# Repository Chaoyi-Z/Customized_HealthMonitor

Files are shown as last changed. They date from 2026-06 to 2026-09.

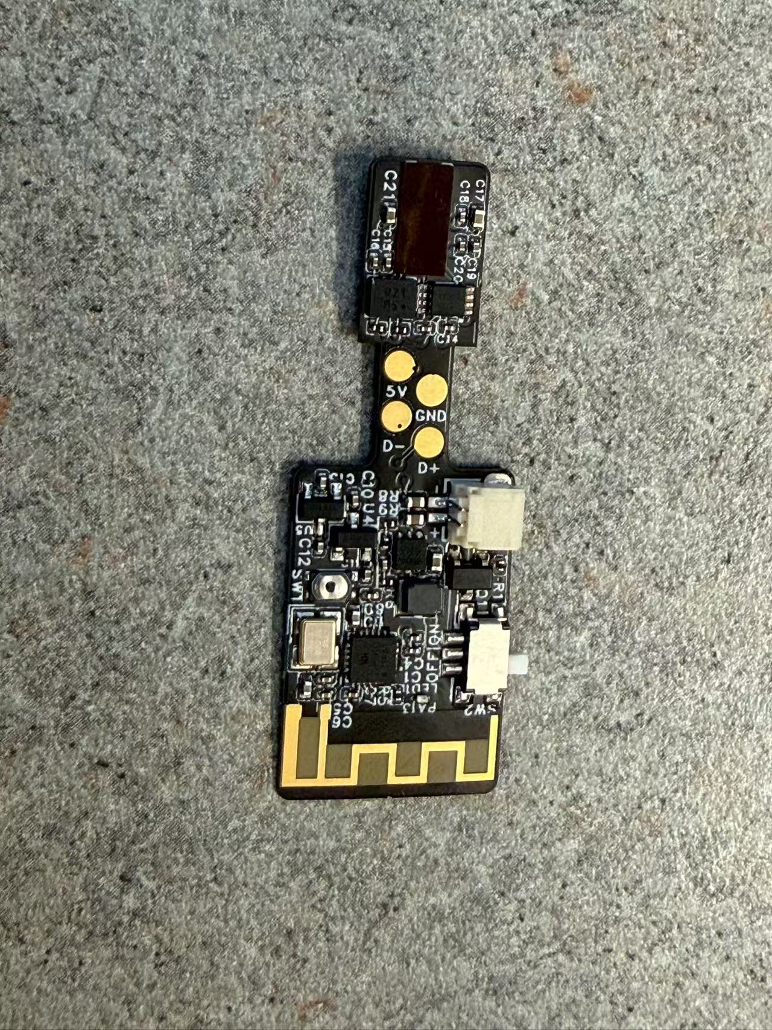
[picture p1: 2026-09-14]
NewBoard/Board_front.jpg

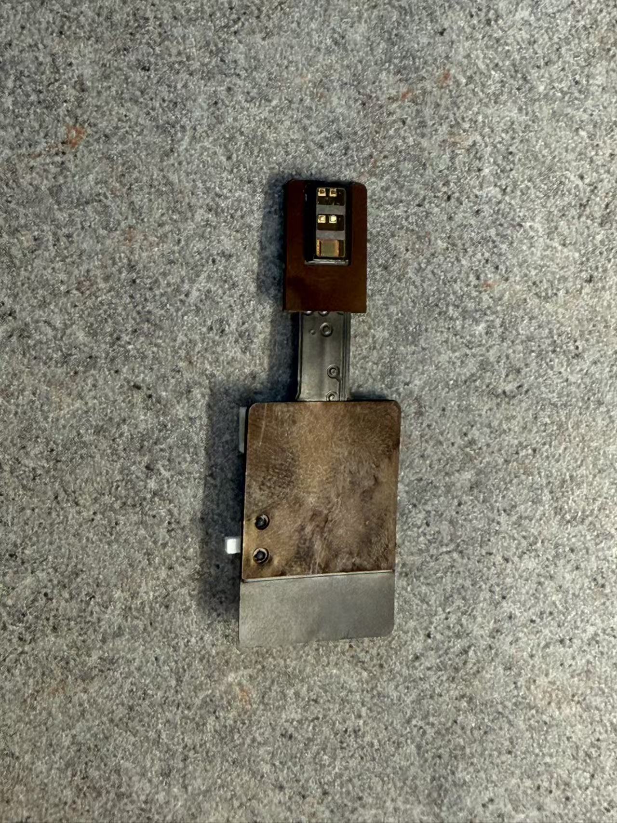
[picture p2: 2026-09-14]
NewBoard/Board_back.jpg

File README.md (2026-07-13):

# ESP32 Health Monitor (BLE)

A wireless physiological monitoring system for marmoset and human subjects. An
ESP32-S3 + MAX30102 streams **Heart Rate, SpO₂, HRV, Skin Temperature, Signal
Quality**, and the **raw PPG waveform** over Bluetooth LE — with real-time
forwarding to [Lab Streaming Layer (LSL)](https://github.com/sccn/labstreaminglayer)
(MonkeyLogic / LabRecorder), **live PC-side beat detection**, and an **offline
NeuroKit2 HRV pipeline**.

---

## Hardware

| Component | Part |
|---|---|
| Microcontroller | ESP32-S3 Dev Module |
| Pulse oximeter | MAX30102 (I²C) |
| Charger | TP4056 (single-cell LiPo) |
| Connection | USB-C (charging + flashing) |

Wiring: MAX30102 SDA → GPIO 8, SCL → GPIO 9 (or as defined in firmware).

---

## Repository layout

```
ESP32_HealthMonitor/ESP32_HealthMonitor.ino   Firmware (Arduino sketch)
health_monitor_gui.py                         Windows BLE GUI + live PC-side HR/HRV
analyze_recording.py                          Offline NeuroKit2 HRV analysis
test_lsl_stream.py                            LSL smoke test
health_monitor_receiver.m                     MATLAB LSL reader
HARDWARE_v2.md, BUDGET_PLAN.md, DEVLOG.md      Design docs / dev log
```

---

## Firmware (`ESP32_HealthMonitor/ESP32_HealthMonitor.ino`)

### Dependencies (Arduino IDE)
- **ESP32 board package** by Espressif (≥ 3.x) — add via Boards Manager
- **SparkFun MAX3010x Pulse and Proximity Sensor Library** — via Library Manager
  ⚠️ If multiple MAX30105 libraries are installed, keep only the SparkFun one.

### Board settings (Arduino IDE 2.x)
| Setting | Value |
|---|---|
| Board | ESP32S3 Dev Module |
| Upload Speed | 460800 |
| USB CDC On Boot | Disabled |
| Port | whichever COM port appears |

### Flashing
**Easiest — Arduino IDE:** open the sketch, pick the board + port, click **Upload**.
The ESP32-S3 uses native USB, so auto-reset often doesn't trigger — if it stalls at
`Connecting…`, do the bootloader dance: **hold BOOT → tap RESET → release BOOT**,
then **re-check Tools → Port** (the COM number can change in bootloader mode) and
Upload again. Use a **USB-C _data_ cable** (many are charge-only).

**Command line (esptool):**
```bash
esptool --chip esp32s3 --port <COM_PORT> --baud 460800 \
  --before no-reset write-flash 0x0 \
  build/esp32.esp32.esp32s3/ESP32_HealthMonitor.ino.merged.bin
```

### BLE service — two characteristics
- **DATA** (NOTIFY, ASCII, ~2.5 Hz) — status string, e.g.:
  ```
  SAMPLING=1,HR=72,SPO2=98,AVG=70,VALID=1,PI=2.4,TEMP=33.5,HRV=38,
  SPECIES=human,CHARGE=battery,FIFO=2,OVF=0,CFG=800/215/1,PROF=4000/300/12000
  ```
- **RAW** (NOTIFY, binary) — the raw PPG waveform in compact little-endian packets
  (3-byte / 18-bit IR & Red samples + real per-sample timestamps + beat markers).
  Lets a host watch the waveform live or re-derive HR/SpO₂/HRV itself.

### Diagnostics (appended to the DATA packet)
| Field | Meaning |
|---|---|
| `CFG=sr/pw/avg` | sensor's **actual** sample rate / pulse width / averaging (register readback) |
| `FIFO=n` | peak MAX30102 FIFO occupancy (of 32) |
| `OVF=n` | cumulative FIFO overflow count (dropped samples) |
| `PROF=r/n/s` | loop profile in µs: per-sample **r**ead / per BLE **n**otify / **S**pO₂ call |

### Sample-rate notes
The effective PPG rate is capped by the **MAX30102's own sample production** — not
BLE, not firmware (confirmed with the diagnostics above: `OVF`=0, tiny notify time,
0% packet loss). The practical sweet spot is **`sampleRate=800, pulseWidth=215µs,
2-LED` → ~250 Hz**. Higher configs counterintuitively produce _slower_. The SparkFun
on-board `checkForBeat()` only tracks reliably near ~20 Hz, so **use the PC-side
detector for HRV** at higher rates. For finer inter-beat timing, the offline analyzer
adds sub-sample peak interpolation.

---

## Python GUI (`health_monitor_gui.py`)

### Install
```bash
pip install bleak pylsl matplotlib numpy scipy
```
Only `bleak` is required; `pylsl` (LSL), `matplotlib` (live plot), and `numpy`/`scipy`
(PC-side HR/HRV) are optional and degrade gracefully if missing.

### Run
```bash
python health_monitor_gui.py
```

### Features
- **PC-side beat detection** — species-aware (bandpass + peak find) HR & HRV computed
  on the host from the raw PPG, independent of the firmware; works at any sample rate.
  This is the **primary HR readout**; the board's own HR is shown as a small diagnostic.
- **Live raw-PPG waveform plot** with beat markers
- Live SpO₂ / PI / Temp / HRV; species toggle (Human / Marmoset)
- **Recording** → status CSV **+** `_raw.csv` (per-sample PPG, with packet `seq`) **+**
  `_beats.csv`; fully instrumented (`cfg`/`fifo`/`ovf`/`prof` columns)
- **Auto-resume** sampling after a BLE reconnect (survives brownout reboots)
- **LSL outlets**: status + raw PPG + beat markers

### LSL channel map (status stream)
| Ch | Label | Unit | Notes |
|----|---|---|---|
| 1 | HR | bpm | −1 = no finger |
| 2 | SpO2 | % | −1 = invalid |
| 3 | HR_avg | bpm | Rolling average |
| 4 | Valid | bool | 1 = good signal |
| 5 | PI | % | Perfusion index |
| 6 | Temp | °C | Skin temperature |
| 7 | HRV | ms | RMSSD |
| 8 | Charge | code | 0=battery 1=charging 2=full |

---

## Offline HRV analysis (`analyze_recording.py`)

Rigorous, publication-grade HRV from a recorded `_raw.csv`, using **NeuroKit2**.

```bash
pip install neurokit2 scipy numpy
python analyze_recording.py path/to/hr_spo2_..._raw.csv [--species human|marmoset]
```

Pipeline: split into device-clock sessions (handles reboots) → gate out
finger-off / low-perfusion segments → species-aware beat detection with **Kubios
artifact correction** and **sub-sample peak interpolation** → full time / frequency /
nonlinear HRV, a per-segment breakdown, and a plot of the longest clean segment.
Species is auto-detected from the companion status CSV.

---

## MonkeyLogic integration

1. Start `health_monitor_gui.py` → click **Start Sampling**
2. In MonkeyLogic **LSL Setup**: set Stream #1 Name = `HealthMonitor`
3. LSL data is auto-recorded in `AnalogData.LSL.LSL1` in the `.bhv2` file

### Read LSL data in MATLAB after recording
```matlab
data = mlread('your_file.bhv2');
all_hr = []; all_spo2 = [];
for i = 1:numel(data)
    lsl = data(i).AnalogData.LSL.LSL1;
    if isempty(lsl), continue; end
    valid = lsl(:,5) == 1;
    all_hr   = [all_hr;   lsl(valid, 2)];   % HR
    all_spo2 = [all_spo2; lsl(valid, 3)];   % SpO2
end
```

---

## Test LSL stream
```bash
python test_lsl_stream.py
```

## Running two boards simultaneously
Give each board a unique name via `DEVICE_NAME` in the firmware and the matching
`DEVICE_NAME` in the GUI; reflash each board. (Default: `HealthMonitor1`.)

---

## Battery life (measured)

On battery at the ~250 Hz config (100 mAh LiPo):
- **~84–92 min total runtime**, reproducible across runs.
- Near end of charge the device **brownout-cycles** — it reboots every ~10–25 min as
  the LiPo sags under load — so only the first ~30 min is unbroken. The GUI's
  auto-resume keeps recording across the reboots.
- Charge _state_ (charging / full / battery) is reported; there is **no battery-%
  gauge** on the v1 board (planned via the BQ25120A PMIC — see `HARDWARE_v2.md`).

| Battery | Rough runtime |
|---|---|
| 100 mAh | ~1.5 hr |
| 200 mAh | ~3 hr |
| 500 mAh | ~5+ hr |

*(~70–90 mA total draw: ESP32-S3 BLE active + MAX30102 LEDs.)*

---

## Authors
- Desimone Lab / Feng Lab, MIT

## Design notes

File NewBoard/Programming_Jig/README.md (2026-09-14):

# Programming jig + battery for the Animal Pulse Sensing flex board (CH591D, Schematic_V3)

## 1. What the debug pads are

The four round pads on the flex neck are the CH591D's **USB** port (PB11 = UD+, PB10 = UD−) plus GND and the board's
own **+5 V boost-converter output** (not a USB power input). The chip is programmed over USB with WCH's ISP bootloader.

Measured from the EasyEDA render (`debug_pad_layout.png`, ±0.05 mm; confirm in EasyEDA before ordering anything):

| Pad | x (mm) | y (mm) | Note |
|-----|---:|---:|---|
| 5V  | −6.09 | −1.21 | boost output — **leave unconnected** |
| GND | −4.50 | +1.11 | |
| D−  | −2.78 | −1.19 | UD− (PB10) |
| D+  | −1.14 | +1.11 | UD+ (PB11) |

Pad Ø 2.15 mm (silk ring Ø 2.39), rows 2.31 mm apart, ~1.65 mm between neighbouring pads along the neck,
neck 5.0 mm wide × ~8 mm long. Coordinates are in the pick-and-place frame (`PickAndPlace_FLEX.xlsx`).

**This is not a standard 2.54 / 2.0 / 1.27 mm pattern, so no off-the-shelf pogo cable or clip fits it.**
Use the printed jig below, or for a one-off flash simply tack-solder three wires (GND, D−, D+) to the pads.

## 2. The jig (files in this folder)

| File | Purpose |
|---|---|
| `pogo_jig_base.stl` | Base plate 56 × 30 × 5 mm with a 0.5 mm pocket in the board outline, a through-slot under the MAX86916, two M3 self-tap holes |
| `pogo_jig_top.stl`  | Pin carrier 7.3 × 28 × 9 mm that drops into the neck notch, 4 pogo holes (Ø1.2) + 2 M3 clearance holes. Already oriented for printing (tongue up) |
| `pogo_jig.scad` | Same geometry, editable. If EasyEDA gives different pad coordinates, edit `pads=[...]` and re-render |
| `pogo_jig_preview.png` | Section views for a sanity check |

Parts to buy:

- 4 × **P75-B1** spring pogo pins (Ø1.02 mm barrel, round head, ~16.5 mm long) — sold in 100-packs on Amazon, e.g. https://www.amazon.com/100pcs-P75-B1-1-02mm-Spring-Loaded/dp/B07BZJ74RC . (Round head "B1" is kinder to gold pads than the pointed "E2".)
- 2 × M3 × 16 mm screws (self-tap into the base plate).
- One sacrificial **USB-A cable** (or a USB-A pigtail). Standard colours: black = GND, white = D−, green = D+, red = +5 V.

The cable (any one of these, see `jig_wiring.png` for the hole-to-wire map):

- **USB-A male to bare-wire pigtail**, e.g. [PATIKIL 3-pack, 28 AWG](https://www.amazon.com/PATIKIL-Pigtail-Extension-Adapter-Charging/dp/B0DWJY8T6Q) or [ELNONE 0.5 m 2-pack](https://www.amazon.com/ELNONE-2Pcs-Short-Pigtail-Wire/dp/B0CKPV3MZR). Thin (28 AWG) is easier to solder to the pin tails than 22–24 AWG.
- **Adafruit 4448 USB-A Plug Breakout Cable** ($1.95, 30 cm, female jumper ends): https://www.adafruit.com/product/4448 . Cut the jumper sockets off and solder the wires, or leave them on and solder a short 0.64 mm header pin to each pogo tail so the sockets push on.
- Any old USB cable cut in half.

Wire colours are standard USB 2.0: pin 1 red = VBUS 5 V, pin 2 white = D−, pin 3 green = D+, pin 4 black = GND. Cheap pigtails sometimes swap colours, so check each wire against the plug pins with a meter first.

Assembly:

1. Print both parts, 0.12–0.2 mm layers, PLA or PETG. If the pin holes print tight, open them with a 1.0 mm drill.
2. Push the pins in from the top until the tips stick out **~1.3 mm below the tongue face** (the raised 4.7 mm strip). Fix with a drop of CA glue on the top side only.
3. Solder black→GND, white→D−, green→D+. **Cut and insulate the red wire** — the board's 5 V pad is an output.
4. Drop the board into the pocket (sensor window down, it goes into the slot), set the pin carrier in the neck notch (the notched corners of both parts go together), tighten the two screws until the carrier sits on the base.

### 2b. Magnetic snap-on version (no screws)

`pogo_jig_base_mag.stl` + `pogo_jig_top_mag.stl` (or set `magnetic=true` in the .scad). Same pad geometry; the two M3 screws are
replaced by two magnet pairs and two alignment pegs. The carrier snaps onto the board one-handed and pulls off with a tilt.

- Magnets: **4 × neodymium discs, Ø4 × 2 mm** (fits `pogo_jig_*_mag.stl`). Amazon listings checked live on 2026-09-03, all Prime-shipped:
  - [MAGNEZMATIC N52 4 mm × 2 mm, 100 pack](https://www.amazon.com/dp/B0HC4G9WGT) — $19.49, 0.94 lb pull each. Best grade; low stock.
  - [AplysiaTech N52 D4×2 mm, 400 pack](https://www.amazon.com/dp/B0F4MYLY85) — $23.99, 4.6★.
  - [BEST CHOICE MAGNETS 4×2 mm, 300 pack](https://www.amazon.com/dp/B0CCXZ1J6N) — $9.99, 4.5★, grade not stated (assume N35, ~70 % of N52 pull; still ample).
  Two N52 pairs give well over 1 kg of clamp against ~0.2–0.4 kg of pogo spring force; N35 still gives roughly 0.7 kg.
  Ø4 × 3 mm discs fit the `pogo_jig_*_mag_4x3.stl` files instead, e.g. [4×3 mm 100 pack](https://www.amazon.com/dp/B0G2RFCBYW) ($9.99, grade not stated) or
  [The Magnet Baron N52 4×3 mm](https://themagnetbaron.com/products/100pcs-4mm-x-3mm-5-32-x-1-8-disc-magnets).
- Pockets: Ø4.15 × 2.1 mm, two in the top face of the base and two in the underside of the carrier, 8 mm either side of the neck centre line.
  Press the magnets in flush and fix with a drop of CA or epoxy. Both faces sit ~0.1 mm below the plastic so the parts mate plastic-to-plastic.
- Alignment: two Ø3 × 2 mm pegs printed on the carrier drop into Ø3.3 holes in the base (12.3 mm either side of centre). Pegs give ±0.15 mm
  registration; the magnets only supply force. If the pegs print oversize, a light pass with a file is enough.
- **Polarity keying**: glue the two base magnets with opposite poles up (north up on the +y side, south up on the −y side), then set the carrier
  magnets so they attract in the correct orientation. A carrier put on backwards is then repelled, which is a second orientation guard on top of the notched corners.
- Keep the magnets on the jig only. A magnet or steel target on the board would add ~0.5–1 g to the wearable, pick up metal debris, and is
  incompatible with any MRI use, which is why a MagSafe-style board connector is not recommended for this device.

## 3. Flashing procedure

- **Never feed USB 5 V into the 5 V pad.** Power the board from its own battery: battery plugged in, USB cable plugged into the PC, then slide SW2 to ON.
- Install **WCHISPTool** (includes the CH372 USB driver): https://www.wch-ic.com/downloads/WCHISPTool_Setup_exe.html .
  Cross-platform CLI alternative: `wchisp` (`wchisp flash firmware.bin`) — https://github.com/ch32-rs/wchisp .
- Chip series CH59x → CH591, interface USB, load the `.hex`/`.bin`, Download.

Bootloader entry facts for the **CH591D (QFN20)**:

- A **blank chip enters the USB bootloader automatically** at power-on (flash address 0 erased). So the first flash of a fresh board "just works".
- Afterwards the bootloader is only entered if **PB7 is low at power-on** (Boot0 for CH591D; PB22 does not exist on this package). PB7 is QFN pin 10 and is **not connected to anything on this board**, so re-flashing needs one of:
  1. Firmware support: e.g. hold SW1 (PA9) at power-on → firmware erases its own first 4 KB (`FLASH_ROM_ERASE(0, 4096)`) and resets, so the bootloader sees blank flash and stays in ISP. (Derived from the documented blank-flash behaviour — test it on the first board before relying on it.) Same thing can be triggered by a BLE command.
  2. Touch QFN pin 10 (PB7) to GND with a fine probe while switching the board on. Awkward on a flex but workable under a scope.
  3. Next board revision: add a PB7 test pad (and ideally a standard 2.54 mm 1×4 or Tag-Connect footprint for the USB pads so a stock pogo clip fits).
- The board's VIO33 rail is 3.0 V, inside the CH591D spec (2.3–3.6 V).

## 4. Battery

CN1 is **JST SH, 1.0 mm pitch, 2-pin, side entry (SM02B-SRSS-TB)**. Mating plug: **JST SHR-02V-S-B**. Input range 3.6–4.2 V (single LiPo).
There is **no charger on the board**, so the cell must be charged externally.

Ready-made cells with the right plug (TinyCircuits, also on Amazon):

| Cell | Size (mm) | Weight | Max discharge | Price | Link |
|---|---|---:|---:|---:|---|
| 150 mAh | 20 × 20 × 5 | 3.8 g | 150 mA | $4.95 | https://tinycircuits.com/products/lithium-ion-polymer-battery-3-7v-150mah |
| 70 mAh  | 15 × 15 × 5 | 1.9 g | 70 mA  | $4.95 | https://tinycircuits.com/products/lithium-ion-polymer-battery-3-7v-70mah |
| 40 mAh  | 20 × 8 × 3.5 | ~1 g | 40 mA | — | https://tinycircuits.com/products/lithium-ion-polymer-battery-3-7v-40mah |

All include a protection PCM. Recommended: **150 mAh** for bench/first animals (headroom for the MAX86916 LED pulses through the 5 V boost), 70 mAh where size matters.
Rough runtime at an estimated 8–20 mA average draw (BLE streaming + PPG + IMU): 150 mAh ≈ 7–18 h, 70 mAh ≈ 3–9 h. Measure it on the real firmware.

Charger with a JST SH socket: **TinyCircuits Tiny Battery Charger** (MCP73831, 100 mA default, micro-USB, $6.95)
https://tinycircuits.com/products/tiny-battery-charger . Adafruit/SparkFun chargers use JST PH 2.0 mm and would need an adapter.

Rolling your own leads: housing **SHR-02V-S-B** + pre-crimped **ASSHSSH28K152** SH jumper (DigiKey), cut in half and soldered to any cell.

**Polarity:** JST SH plugs are not standardised. With the antenna to the right and SW2 at the top, the CN1 pin nearest the neck is
"−" and the outer pin is "+" (silkscreened). Check with a meter that the red lead lands on "+". The board has a P-MOSFET reverse-polarity
guard (Q1), so a swapped plug will not damage anything — it just won't power up; swap the crimps in the housing to fix it.
Switch SW2 OFF before plugging or unplugging the cell.

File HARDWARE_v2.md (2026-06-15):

# ESP32 Health Monitor — Hardware v2 (Shrink Revision)

Target form factor: **~15 × 25 mm main board** + MAX30102 flex tail (unchanged).
Goal: wearable-grade for marmoset harness mounting.

---

## Headline change

Replace **three separate power chips + slide switch + BOOT button** with **one PMIC**:

| v1 (current) | v2 (new) |
|---|---|
| TP4056 (charger, SOP-8) | **BQ25120A** (2.5 × 2.6 mm WCSP-25) |
| ME6217 (3.3V LDO, SOT-23-5) | …integrated 3.3V buck in BQ25120A |
| XC6206 (1.8V LDO, SOT-23-5) | …integrated LDO in BQ25120A (set to 1.8V) |
| MSK12C02 slide switch | …integrated push-button manager in BQ25120A |
| SW1 BOOT button | **eliminated** — replaced by OTA + emergency solder pads |
| SW2 ENABLE button | **kept** — wired to BQ25120A MR/PB pin |

**Net result:** 4 ICs → 1 IC, 2 buttons → 1 button. Saves ~60% of power-section area and eliminates all the broken-button headaches.

---

## TI BQ25120A — why it's the right PMIC

A single 2.5 mm chip that does:

- **Linear charger** for single-cell LiPo, programmable 5–300 mA via I²C
- **3.3V buck converter** (300 mA max, 92% efficient at typical loads)
- **Programmable LDO** (100 mA, set to 1.8V for MAX30102 VLED rail)
- **Push-button controller** — short press wakes/sleeps, long press hard-reset
- **700 nA ship-mode current** — board sleeps for months on a full battery
- **Battery voltage monitor** with I²C readout (no more GPIO guessing for charge state)
- **I²C control** — share the same bus as MAX30102

Cost: ~$2.50 at DigiKey, available at LCSC for JLCPCB assembly.

---

## Power tree (v2)

```
USB-C 5V ──┐
           ├──► BQ25120A.VIN
Charge pads┘
                    │
                    ├──► CHG → BAT pin → LiPo 100 mAh
                    │
                    ├──► SYS (3.3V buck, 300mA) ──► ESP32-S3 3V3, MAX30102 VDD
                    │
                    ├──► LS/LDO (1.8V, 100mA)   ──► MAX30102 VLED+
                    │
                    ├──► MR/PB ◄── push button (SW_PWR) ─── GND
                    │
                    └──► SDA/SCL/INT ──► ESP32-S3 I²C bus + GPIO

Push button behavior (firmware handles):
  • Short press (<2s)  → wake from deep sleep / start sampling
  • Long press  (>3s)  → hard reset (BQ25120A handles in hardware)
  • Held during boot   → enter bootloader (via firmware check at startup)
```

---

## Schematic block diagram (text)

```
┌──────────────────┐        ┌─────────────────────┐
│   USB-C          │        │   ESP32-S3-MINI-1   │
│   ──────────     │        │                     │
│   VBUS ──────────┼──────► │ 3V3 ◄─── from BQ.SYS│
│   D+/D- ◄────────┼────────│ IO19/IO20 (USB)     │
│   GND            │        │ IO8/IO9 (I²C bus)   │──┐
└──────────────────┘        │ IO0  (boot, exp pad)│  │
                            │ EN   (chip enable)  │  │
                            │ IO4  (MAX int)      │  │
                            │ IO6  (BQ int)       │  │
                            └─────────────────────┘  │
                                                      │
┌──────────────────────────────────────────┐         │
│  BQ25120A  (2.5 × 2.6 mm WCSP-25)        │         │
│                                          │         │
│  VIN  ◄─── 5V from USB-C / charge pads   │         │
│  BAT  ◄──► LiPo +  (100 mAh)             │         │
│  SYS  ────► 3.3V to ESP32 + MAX VDD      │         │
│  LDO  ────► 1.8V to MAX VLED+            │         │
│  MR   ◄─── SW_PWR push button ─── GND    │         │
│  SDA  ◄───┐                              │         │
│  SCL  ◄───┼── shared I²C bus ◄───────────┼─────────┘
│  INT  ────┘    (also to MAX30102)        │
└──────────────────────────────────────────┘
                                                      
┌─────────────────────────────────┐                  
│  MAX30102 on flex tail          │                  
│  VDD   ◄── 3.3V from BQ.SYS     │                  
│  VLED+ ◄── 1.8V from BQ.LDO     │                  
│  SDA/SCL ◄── shared I²C bus     │                  
│  INT     ────► ESP32 IO4        │                  
└─────────────────────────────────┘                  

┌─────────────────────────────────┐
│  Emergency boot pads            │
│  GPIO0 ─── solder pad TP_BOOT   │  ← bridge to GND
│  GND   ─── solder pad TP_GND    │     with tweezers
│                                 │     only if OTA fails
│  EN    ─── solder pad TP_EN     │  ← reset signal
└─────────────────────────────────┘
```

---

## BOM (key parts only — for JLCPCB/LCSC ordering)

| Ref | Part | Package | LCSC # | Notes |
|-----|---|---|---|---|
| U1 | ESP32-S3-MINI-1 | LGA-65 | C2913203 | Same as v1 |
| U2 | TI BQ25120AYFPR | WCSP-25 (2.5×2.6mm) | C2654987 | The PMIC |
| U3 | MAX30102EFD+T | OESIP-14 | C89215 | Same as v1, on flex tail |
| L1 | 2.2 µH inductor | 0805 | C167221 | For BQ25120A buck |
| C_in | 4.7 µF / 10 V | 0402 | C19666 | BQ25120A VIN cap |
| C_bat | 4.7 µF / 10 V | 0402 | C19666 | BAT pin cap |
| C_sys | 10 µF / 10 V | 0603 | C19702 | SYS output cap |
| C_ldo | 1 µF / 10 V | 0402 | C15849 | LDO output cap |
| SW_PWR | Tactile 3.5×3.5mm | SMD | C720477 | Power/wake button |
| J1 | USB-C 6-pin power-only | THT/SMD | C165948 | Or omit + use pads |
| J2 | 1.25mm 2-pin JST | SMD | C2685120 | LiPo connector |

All passives in **0402** to save space. Pull-ups for I²C: 4.7 kΩ on SDA/SCL (already required by MAX30102).

---

## PCB layout notes

1. **2-layer PCB is fine** — 4-layer only helps with very tight routing or impedance control. Stick with 2-layer to keep cost down.
2. **Components on both sides** — ESP32 module on top, BQ25120A + passives on bottom. Cuts area roughly in half.
3. **Antenna keepout** — the ESP32-S3-MINI-1 antenna sticks off one edge; that edge must have **no copper, no ground plane, no parts** within 15 mm of the antenna pattern. Easiest: orient the module so the antenna hangs over the corner of the PCB.
4. **MAX30102 flex tail** — keep the existing footprint. A 4-conductor 0.5 mm pitch flex cable connector (or just direct solder pads on the flex) carries SDA, SCL, INT, VDD, GND, VLED+.
5. **Emergency boot pads** — three 1.5 mm² gold pads on the bottom labeled `BOOT`, `EN`, `GND`. Used only if OTA flash fails.
6. **Test points** for BAT+, SYS, 1.8V, GND on the bottom for debugging.

---

## Where to get this made

You have three tiers depending on how much you want to do yourself:

### Tier 1 — fully outsourced (recommended for first prototype)

**JLCPCB + PCBA service** (Shenzhen, China)
- Upload Gerbers + BOM + pick-and-place file from EasyEDA or KiCad
- They source parts from LCSC, assemble, and ship in 7–10 days
- Cost for 5 fully assembled boards (with BQ25120A): **~$60–90 total**
- URL: https://jlcpcb.com/  → upload → tick "PCB Assembly"
- Best price/performance ratio in the industry right now
- ESP32-S3-MINI-1 and BQ25120A are both in their **Basic Parts** library (no extended-parts fee)

**PCBWay** (Shenzhen, China)
- Slightly more expensive (~$80–120 for 5 assembled) but better customer service and faster turnaround for complex builds
- URL: https://www.pcbway.com/
- Good if you want them to source unusual parts that LCSC doesn't carry

**Seeed Fusion** (Shenzhen, China)
- Similar pricing to JLCPCB, better for small flex-PCB orders
- URL: https://www.seeedstudio.com/fusion.html
- Use this for the MAX30102 flex tail if you redesign it

### Tier 2 — bare PCB only, you do assembly

**OSH Park** (Portland, OR, USA)
- Premium 2-layer PCBs in purple soldermask, made in USA
- ~$5–15 per 3 boards depending on size, ~2 week turnaround
- URL: https://oshpark.com/
- Use this if you want US-made PCBs and don't mind soldering yourself
- You'd then buy components from DigiKey/Mouser and assemble with a hot air station or reflow oven

### Tier 3 — in-house at MIT

You have free or low-cost access to:

- **MIT.nano fab** (Building 12) — PCB milling on the LPKF, SMD reflow oven, paste stencils. Free for MIT users with training. https://mitnano.mit.edu/
- **MIT Edgerton Center Maker Space** (4-409) — pick-and-place, reflow, hand assembly stations. Good for the BQ25120A WCSP package since they have proper tooling. https://edgerton.mit.edu/
- **MIT MakerWorks** (Hobby Shop area) — basic SMD soldering stations
- **Beaverworks** at Lincoln Lab — if you have a faculty sponsor, they have professional PCB assembly equipment

For the 2.5 mm WCSP BQ25120A specifically, you really want **machine placement + reflow oven**. Hand-soldering a 25-ball WCSP is possible but painful. The MIT.nano LPKF + ProtoFlow oven combo is the best free option.

---

## My recommended path for you

1. **Design** the schematic + PCB in **EasyEDA** (free, web-based, integrated with JLCPCB)
2. **Order assembled prototypes** from JLCPCB — 5 boards for ~$70 total, 10 days
3. **Once it works**, you can either keep using JLCPCB for production runs (up to ~100 boards still cost-effective) or move to a US-based assembler if MIT requires it for grant-funded work

For your marmoset application, 5–10 boards from JLCPCB is plenty for the foreseeable future. The BQ25120A is in their library, the ESP32-S3-MINI-1 is in their library, MAX30102 is in their library — zero extended-parts fees.

If you want, the next step is to actually draw the schematic in EasyEDA and generate the Gerbers. I can guide you through the EasyEDA UI step-by-step, or you can hand this document to an undergrad / Edgerton tech and they can do the layout in a few hours.

---

# Flex PCB / Tail-Wrap Edition

For the marmoset tail-mount use case, a **rigid-flex hybrid** PCB is the right architecture. Pure flex doesn't work because the ESP32-S3 module, the BQ25120A, the USB-C connector, and the LiPo battery are all rigid — they need rigid PCB sections. But the *connections between them*, and especially the sensor section that contacts the tail, can be flex.

## Recommended architecture: "two islands + tail"

```
  ┌──────────────┐                                                    ┌─────────┐
  │ RIGID MAIN   │═══════ flex cable (40-80 mm) ═══════════════════════│ FLEX    │
  │ ISLAND       │                                                    │ TAIL    │
  │ ~15 × 18 mm  │                                                    │ WRAP    │
  │              │                                                    │ ~10×30mm│
  │ • ESP32-S3   │                                                    │         │
  │ • BQ25120A   │                                                    │ MAX30102│
  │ • USB-C/pads │                                                    │ + LEDs  │
  │ • Power btn  │                                                    │         │
  │ • LiPo glued │                                                    │         │
  │   to back    │                                                    │         │
  └──────────────┘                                                    └─────────┘
       ↑                                                                  ↑
  Worn on harness /                                                  Wraps around
  vest / collar                                                      tail base,
                                                                     sensor faces in,
                                                                     velcro/silicone
                                                                     band over it
```

**Why this split:**

1. The marmoset is ~300–400 g. The max comfortable device weight is ~30 g (10 % body mass rule for chronic implants). A LiPo battery is the heaviest single item — you do **not** want it on the tail. Body-mounted main island keeps weight off the tail.
2. The tail is mobile and gets bitten/scratched. Keeping only the cheap sensor section on the tail means damage there doesn't kill the expensive ESP32 + battery.
3. The flex cable acts as a strain relief between the two — if the marmoset yanks the sensor, the flex flexes instead of ripping the main board apart.

## The tail-wrap flex section

Dimensions matched to marmoset tail anatomy:

| Parameter | Value | Why |
|---|---|-----|
| Wrap width | 8–10 mm | Wide enough to not migrate, narrow enough to flex easily |
| Wrap length | 35–40 mm | Marmoset tail base circumference ~25 mm + 10–15 mm overlap for fastening |
| Sensor pad position | Centered, 12 mm from one end | LEDs face the underside of the tail (less hair, better perfusion) |
| Total flex thickness | 0.1–0.15 mm (polyimide) | Conforms tightly to skin without buckling |
| Stiffener at sensor | 0.4 mm FR4 island, 5 × 5 mm | Keeps MAX30102 flat against skin, distributes pressure |

**Fastening:** The simplest and least invasive option is a thin **silicone band** or **Coban veterinary wrap** over the entire flex wrap. Avoid Velcro — it catches fur. The flex itself does *not* need adhesive — friction + the wrap keeps it in place.

**Hair management:** Marmoset tail hair will block the MAX30102 LEDs. Two options:
- **Shave a small (~8×8 mm) spot** under the sensor at the start of the experiment. Hair regrows in ~2–3 weeks.
- **Use a small clear silicone "window"** as a hair-displacing optical coupler. Press-fit into the FR4 stiffener cutout. This is what wearable pulse-ox devices like Owlet use.

## Flex PCB stack-up

For JLCPCB / Seeed Fusion flex:

```
Top coverlay (polyimide, 25 µm) ────────────┐
Top adhesive (12 µm) ─────────────────────┐ │
Top copper trace (35 µm / 1 oz) ────────┐ │ │
Polyimide base (50 µm) ───────────────┐ │ │ │
Bottom copper trace (35 µm) ────────┐ │ │ │ │
Bottom adhesive (12 µm) ──────────┐ │ │ │ │ │
Bottom coverlay (polyimide, 25µm) │ │ │ │ │ │
                                  ▼ ▼ ▼ ▼ ▼ ▼
Total thickness: ~0.15 mm
```

For rigid sections (ESP32 main island, MAX30102 stiffener), the flex laminates onto **0.4 mm or 0.6 mm FR4** islands. Don't go thicker on the islands — extra stiffness creates stress concentrations where rigid meets flex.

**Critical layout rules:**
- No traces perpendicular to the bend axis — route 45° to the bend
- No vias within 1 mm of a flex bend
- Tear-drop pads at all rigid-to-flex transitions
- Coverlay opening only at component pads and the sensor window

## Where to get flex / rigid-flex made

This is where vendor choice matters a lot — not all PCB houses do flex well.

| Vendor | Flex quality | PCBA on flex? | Cost (5 boards) | Notes |
|---|---|---|---|---|
| **Seeed Fusion** ⭐ | Excellent | Yes, full PCBA | **$120–180** | Best one-stop shop for prototypes. Has dedicated flex+rigid-flex assembly. |
| **PCBWay** | Excellent | Yes | $150–250 | Premium quality, slower turnaround |
| **JLCPCB** | OK for plain flex, limited rigid-flex | Limited (no PCBA on rigid-flex yet) | $80–120 (bare boards) | Cheapest for plain flex; you'd assemble the rigid sections yourself or send to a separate assembler |
| **Flexible Circuit Technologies (FCT)** | Excellent (US) | Yes | $400–800 | US-based, ITAR-compliant, slow (4-6 weeks). Use only if MIT grant requires US fab |
| **All Flex Solutions** (MN, USA) | Excellent (US) | Yes | $300–600 | Aerospace-grade, ITAR option, US-based |
| **Trackwise** (UK) | Excellent | Yes | £400+ | UK-based, very long flex specialty (meter-scale) |

**My recommendation for the marmoset prototype:** **Seeed Fusion** rigid-flex + PCBA service. ~$150 for 5 assembled boards including the BQ25120A, ESP32 module, MAX30102, and the polyimide flex tail. They have a dedicated rigid-flex line and won't try to talk you out of the design like JLCPCB might.

## Weight budget for marmoset (rough estimate)

| Component | Mass |
|---|---|
| Main rigid island (15×18 mm, 2-layer, 1.0 mm FR4) | ~1.2 g |
| ESP32-S3-MINI-1 module | 0.5 g |
| BQ25120A + passives | 0.1 g |
| LiPo 100 mAh (10×15×3.5 mm) | 2.2 g |
| Flex cable (40 mm × 8 mm × 0.15 mm) | 0.05 g |
| Tail wrap section + FR4 stiffener + MAX30102 | 0.4 g |
| Silicone band (10 mm × 35 mm) | 0.3 g |
| **Total** | **~4.7 g** |

A 400 g marmoset can carry this all day with no apparent discomfort (well under the 10 % rule). For a 300 g marmoset you'd want a 50 mAh battery instead (~1.1 g) to stay under 4 g total.

## Sensor placement on the tail

For a marmoset tail:

```
        ─── base of tail (where fur is densest) ──────► tip
       │                                                  │
       │     ↑ Mount the sensor here:                     │
       │     • 25–40 mm from the base                     │
       │     • Underside (less hair, better perfusion)    │
       │     • Above the ventral artery (visible vein)    │
       │                                                  │
       └──────────────────────────────────────────────────┘
              ↑
   Mark this spot with a tiny tattoo or shaved patch
   on day 1 so subsequent measurements are at the same
   anatomical location (consistency for chronic studies)
```

The MAX30102's red (660 nm) + IR (880 nm) wavelengths penetrate ~5 mm into tissue. Marmoset tail at this location is ~6–8 mm thick — perfect for reflectance pulse-ox geometry. SpO₂ should be reliable; HR is guaranteed reliable.

## Validation before going to production

Before you commit to a fab order, do **two cheap things first**:

1. **Mock up the wrap with a piece of 0.15 mm polyimide tape** + the existing PCB's MAX30102 flex tail. Tape it to a marmoset tail (or your own finger, then a colleague's wrist as a proxy for the tail's curvature) and verify signal quality and comfort. The current v1 PCB already has the MAX30102 on a flex pigtail — you can test the wrap concept *today*.

2. **3D print a tail dummy** (5 mm diameter, 50 mm long, in soft TPU at 95A hardness) to test fastening and signal stability under simulated motion. This catches a lot of mechanical problems before paying for a $150 flex PCB run.

If both of those work, then commit to the Seeed Fusion order with confidence.

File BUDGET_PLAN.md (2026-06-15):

# ESP32 Health Monitor — $1,500 Build Budget Plan

**Goal:** From current v1 prototype → 8–10 production-ready marmoset tail-wrap units, with 2 design iterations along the way to catch and fix problems before committing to the final batch.

**Timeline:** ~6–8 weeks (3 PCB iterations × 10 days each + testing time between).

**Total budget target:** $1,500 (with $500 reserve for surprises, bringing to $2,000 ceiling).

---

## Why this phasing matters

Custom rigid-flex PCBs cost $150–200 per 5-board run. The first design will have at least one thing wrong — wrong pad layout, missed pull-up, antenna keepout violation, sensor window in the wrong place, battery doesn't fit, etc. That's normal. Plan for **3 PCB runs**:

1. **Run 1 (verify electronics)**: Plain rigid PCB, no flex yet, just confirm the BQ25120A circuit works
2. **Run 2 (verify mechanics)**: Rigid-flex with the tail wrap, fit-check on actual marmoset
3. **Run 3 (production)**: Final 10–15 boards based on what runs 1 & 2 taught you

Skipping straight to Run 3 with no validation is the #1 way to spend $2000 and end up with 10 boards that don't fit. Don't do that.

---

## Phase 0 — Validation with current v1 board ($60, week 1)

Before spending any PCB money, validate the **tail-wrap concept** with the hardware you already have. The v1 PCB has the MAX30102 on a flex pigtail — that's all you need to test geometry and signal quality.

| Item | Vendor | Cost |
|---|---|---|
| 3D-printed TPU tail dummies (5–8 mm dia, 95A hardness, 50 mm long, qty 5) | MIT Edgerton 3D printer or Shapeways | ~$15 |
| Polyimide / Kapton tape, 6 mm wide × 33 m roll | Amazon | $8 |
| 3M Coban self-adherent wrap, 1" × 5 yd, qty 4 rolls | Amazon | $15 |
| Medical-grade silicone tubing 6 mm ID (for skin-coupling tests) | McMaster-Carr 5236K232 | $12 |
| Finger pulse oximeter (Masimo MightySat or similar) for ground-truth comparison | Amazon | $50 |
| Hair clipper, fine animal-grade (Wahl Bravura) | Amazon | $80 |

**Subtotal: ~$180** (over by $20 — drop the hair clipper if your facility already has one; most marmoset rooms do)

**Deliverable:** Confirmed signal quality on a curved tail-sized surface, with motion. If this fails, no point ordering custom flex PCBs.

---

## Phase 1 — First custom PCB (electronics validation, $230, week 2-3)

Goal: validate the **BQ25120A power section + ESP32 + MAX30102** on a rigid PCB before adding the complexity of flex. Keep the form factor the same as v1 (~30×40 mm) so debugging is easy.

| Item | Vendor | Cost |
|---|---|---|
| Rigid 2-layer PCB + PCBA, 5 boards assembled | **JLCPCB** | $70 |
| Extended-parts surcharge (if BQ25120A not in basic library) | JLCPCB | $25 |
| Spare BQ25120A chips (qty 5) | DigiKey | $14 |
| Spare ESP32-S3-MINI-1 modules (qty 3) | DigiKey | $15 |
| Spare MAX30102 sensors (qty 5) | DigiKey | $25 |
| LiPo batteries, 100 mAh, qty 5 (PKCELL 401020 or similar) | Adafruit | $25 |
| LiPo batteries, 50 mAh, qty 5 (smaller for tail-mount tests) | Adafruit | $35 |
| Shipping (JLCPCB DHL, ~3 days) | JLCPCB | $20 |

**Subtotal: ~$230**

**Deliverable:** 5 working boards with the new PMIC architecture, verified to:
- Charge from USB-C
- Run on battery with deep sleep (<20 µA)
- Wake on push button
- I²C battery voltage readout works
- BLE range matches v1
- MAX30102 still works on both 1.8V and 3.3V rails

If this passes, you're confident the electronics design is correct and ready to commit to the flex version. If something fails (it probably will — first runs always have issues), debug, redesign, send Run 1b ($90 for re-spin).

**Budget reserve for Run 1b respin: $90.**

---

## Phase 2 — Rigid-flex prototype (mechanical validation, $280, week 4-5)

Goal: take the working electronics from Phase 1 and put them on the actual rigid-flex form factor. Test fit on a marmoset (or proxy).

| Item | Vendor | Cost |
|---|---|---|
| Rigid-flex PCB + PCBA, 5 boards assembled | **Seeed Fusion** | $170 |
| Rush production option (5 days vs 10) | Seeed | $40 |
| Custom 3D-printed harness/vest for marmoset (TPU 95A, fitted to ~350g animal) | MIT Edgerton + your animal's measurements | $30 |
| Medical-grade silicone elastic bands, various sizes (Polymer Plastics 1/8" × 3/8" × 1") | McMaster-Carr | $25 |
| Tegaderm transparent dressing (for skin-side attachment tests) | Amazon | $20 |
| Shipping (Seeed DHL) | Seeed | $25 |

**Subtotal: ~$310** (over by $30 — skip rush production if not time-critical, saves $40)

**Deliverable:** 5 wearable units fit-tested on a marmoset or marmoset-sized proxy. You'll learn:
- Does the wrap stay on without irritation?
- Is the cable strain relief adequate?
- Does motion cause sensor liftoff?
- Is the battery life realistic for a session (target: 4+ hours active, days idle)?

Almost certainly you'll need a Run 2b respin to fix something mechanical. Common findings: cable too short, wrap too narrow, sensor window misaligned, harness mount in wrong spot.

**Budget reserve for Run 2b respin: $200.**

---

## Phase 3 — Production batch ($380, week 6-7)

Goal: order the final batch of devices for actual experiments. Quantity = number of marmosets in your study + 30% spares for failures.

Assuming 6 animals in the study:

| Item | Vendor | Cost |
|---|---|---|
| Rigid-flex PCB + PCBA, 10 boards assembled (production) | Seeed Fusion | $280 |
| 10 × LiPo 50 mAh tail-friendly batteries | Adafruit | $70 |
| 10 × custom-fit harnesses (one per animal) | MIT Edgerton | $50 |
| Bulk Coban wrap (12 rolls, 3M brand) | Amazon | $35 |
| Bulk silicone bands (50 pieces) | McMaster | $25 |
| Shipping | Seeed | $25 |

**Subtotal: ~$485** (over by $105 — order 8 boards instead of 10 if tight, saves $80)

**Deliverable:** 8–10 production units ready for live experiments.

---

## Phase 4 — Tooling and spares ($150, ongoing)

Stuff that pays for itself across the whole project. Buy at start of Phase 1.

| Item | Vendor | Cost |
|---|---|---|
| USB microscope, 1000× (for inspecting BQ25120A WCSP solder joints) | Amazon | $45 |
| Saleae logic analyzer clone (for I²C debugging) | Amazon | $15 |
| ESD-safe precision tweezers, qty 2 | DigiKey | $20 |
| Magnifying lamp w/ ring light | Amazon | $40 |
| Isopropyl 99% (1 L, for cleaning) | Amazon | $12 |
| Flux pen (for solder rework) | DigiKey | $8 |
| Spare USB-C cables (3 ft, qty 3, USB-IF certified) | Anker | $20 |

**Subtotal: ~$160**

You already have access to MIT.nano and Edgerton, so no need to buy a reflow oven, hot air station, or oscilloscope. If you didn't have campus access, add $300 for a TS100 / hot air rework station combo.

---

## Total budget summary

| Phase | Cost | Cumulative |
|---|---|---|
| Phase 0 — Validation kit | $180 | $180 |
| Phase 1 — Electronics PCB | $230 | $410 |
| Phase 1b reserve (respin) | $90 | $500 |
| Phase 2 — Rigid-flex prototype | $310 | $810 |
| Phase 2b reserve (respin) | $200 | $1,010 |
| Phase 3 — Production batch | $485 | $1,495 |
| Phase 4 — Tools & spares | $160 | $1,655 |
| **Hidden contingency (shipping fees, customs, mistakes)** | $250 | **$1,905** |

**Lands you at ~$1,900 out of a $2,000 ceiling, with all 8–10 production units in hand.**

If you stay disciplined and Run 1 and Run 2 succeed on first try (rare but possible), you can land at ~$1,400 and use the remainder for extra spares or a publication-quality enclosure.

---

## Vendors at a glance

| Vendor | What | Why |
|---|---|-----|
| **JLCPCB** | Plain rigid PCB + PCBA | Cheapest first-iteration (Phase 1) |
| **Seeed Fusion** | Rigid-flex + PCBA | Best rigid-flex shop for prototype quantities |
| **DigiKey** | Spare components, fast US shipping | Same-day stock for emergency parts |
| **Adafruit** | LiPo batteries with JST, breakout boards | Friendly small quantities, good docs |
| **McMaster-Carr** | Silicone bands, tubing, mechanical hardware | Next-day NY delivery, no minimum |
| **MIT Edgerton Center** | 3D printing, hand assembly help | Free w/ MIT ID, on-campus |
| **MIT.nano** | Reflow oven, PCB milling backup | Free w/ MIT training |

---

## What to NOT spend money on

| Tempting purchase | Why skip |
|---|---|
| Premium US PCB house (OSH Park, FCT) for prototypes | 5× cost for marginal quality improvement — overkill until you're shipping units to other labs |
| Custom injection-molded enclosure | Not needed for n=6 animals. Use the rigid-flex PCB + silicone band as-is. Mold tooling is $5k+ |
| Bluetooth Mesh / Thread / LoRa | BLE 5 already does what you need with MonkeyLogic LSL |
| Bigger battery (200+ mAh) | More weight on the tail. 50–100 mAh is plenty at BLE's ~15 mA draw — that's 3–6 hours active, weeks idle |
| Pulse oximetry FDA certification | Research use, not medical device. Save it for a clinical translation later |
| OLED display on the board | Battery drain, adds weight, you have the GUI on the laptop already |

---

## Recommended order of purchases (next 7 days)

1. **Today**: Order Phase 0 validation kit from Amazon ($180). Arrives in 2 days.
2. **This week**: Validate the tail-wrap concept with v1 PCB + Phase 0 materials. If it works, schematic for v2 in EasyEDA.
3. **End of week 1**: Submit Phase 1 PCB order to JLCPCB. 10-day lead time. Order spare components from DigiKey same day (next-day delivery).
4. **Week 2**: While waiting on PCBs, build the v6 GUI integration (LSL → MonkeyLogic verification).
5. **Week 3**: Phase 1 boards arrive, bring-up week. Confirm BQ25120A works.
6. **Week 4**: Order Phase 2 rigid-flex from Seeed.
7. **Week 5-6**: Fit checks, animal trials with Phase 2 boards.
8. **Week 7**: Phase 3 production order, locks the design.
9. **Week 8**: Final units in hand, ready for experiments.

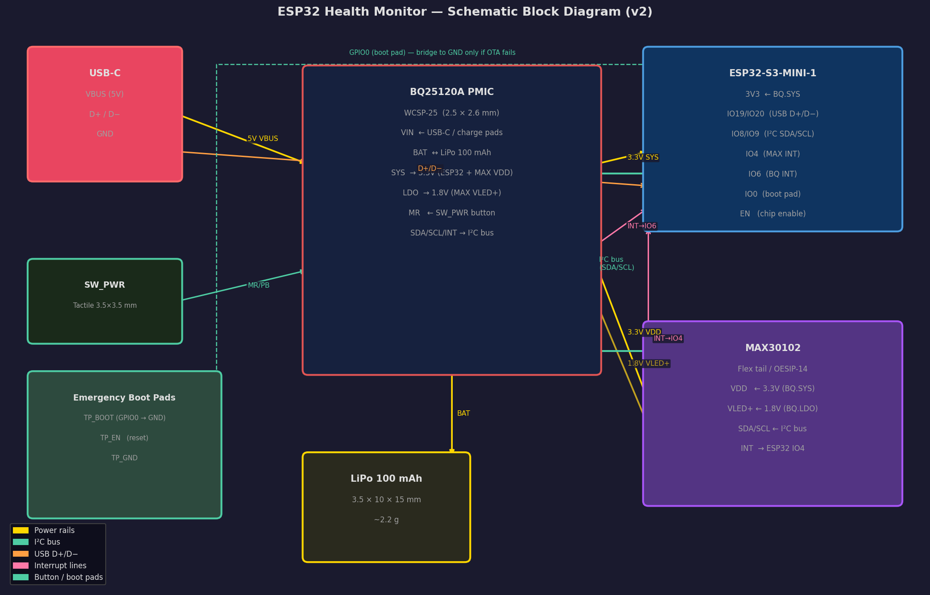
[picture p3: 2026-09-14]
schematic_block_diagram.png

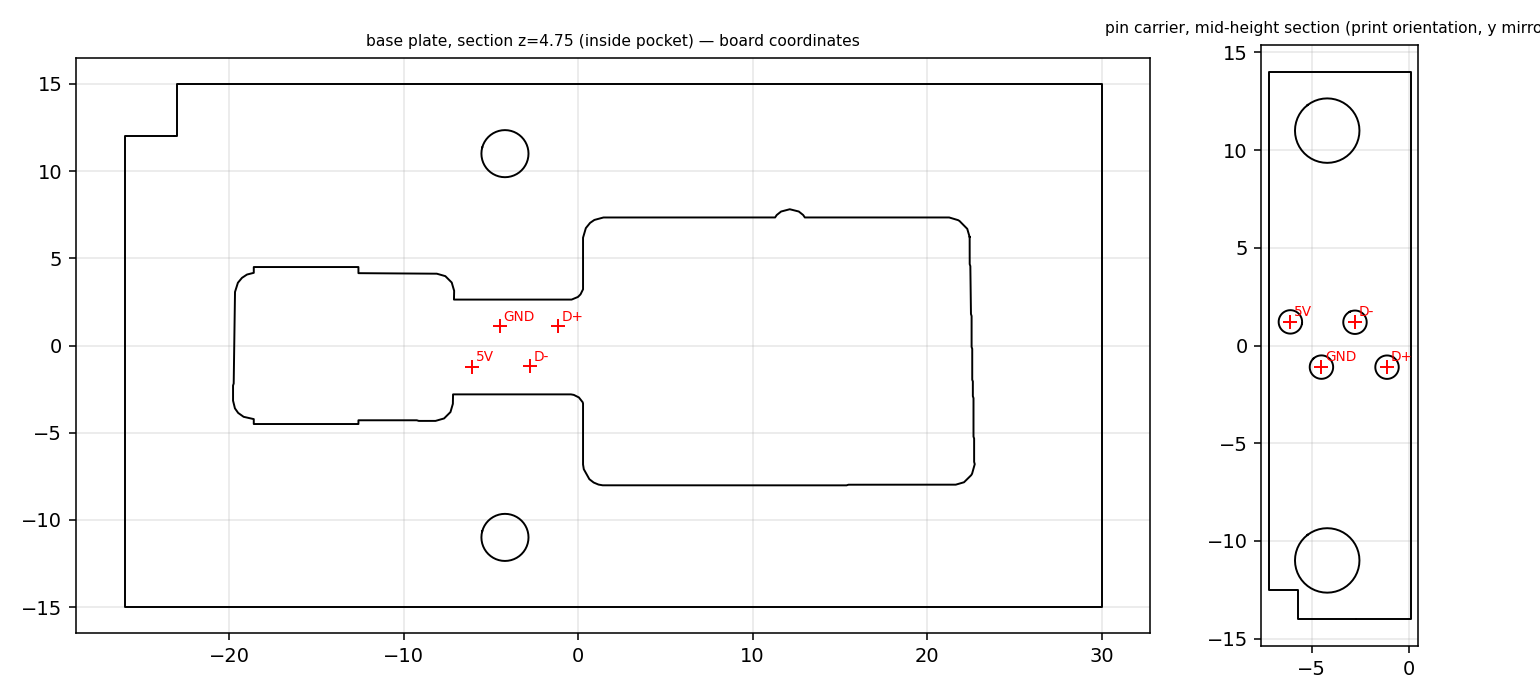
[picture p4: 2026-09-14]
NewBoard/Programming_Jig/pogo_jig_preview.png

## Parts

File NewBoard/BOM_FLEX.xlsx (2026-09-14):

Quantity | Comment | Designator | Footprint | Value | Manufacturer Part | Manufacturer | Supplier Part | Supplier
10 | 100nF | C1,C4,C7,C8,C9,C14,C15,C16,C18,C20 | C0201 | 100nF | TCC0201X5R104K100ZT | CCTC(三环) | C5142565 | LCSC
2 | 12pF | C2,C3 | C0402 | 12pF | 0402CG120J500NT | FH(风华) | C1547 | LCSC
2 | 470nF | C5,C6 | C0201 | 470nF | GRM033R60J474KE90D | muRata(村田) | C85926 | LCSC
5 | 4.7uF | C10,C11,C12,C13,C19 | C0201 | 4.7uF | GRM035R60J475ME15D | muRata(村田) | C335103 | LCSC
4 | 10uF | C17,C22,C23,C24 | C0402 | 10uF | CL05A106MQ5NUNC | SAMSUNG(三星) | C15525 | LCSC
1 | 1uF | C21 | C0402 | 1uF | CL05A105KA5NQNC | SAMSUNG(三星) | C52923 | LCSC
1 | 10nF | C25 | C0201 | 10nF | 0201B103K250NT | FH(风华) | C285010 | LCSC
1 | Battery | CN1 | CONN-SMD_2P-P1.00_SM02B-SRSS-TB-LF-SN |  | SM02B-SRSS-TB(LF)(SN) | JST | C160402 | LCSC
1 | 2.2uH | L1 | IND-SMD_L2.5-W2.0_SWPA252012S | 2.2uH | 74404024022 | Wurth(伍尔特) | C2046874 | LCSC
1 | PA13 | LED1 | LED-SMD_L0.65-W0.35-P0.41_XL-0201SURC |  | XL-0201SURC | XINGLIGHT(成兴光) | C3646923 | LCSC
1 | AO3401A | Q1 | SOT-23-3_L2.9-W1.3-P1.90-LS2.4-BL-2 |  | AO3401A | AOS | C15127 | LCSC
2 | 1MΩ | R1,R8 | R0201 | 1MΩ | RC0201JR-071ML | YAGEO(国巨) | C163497 | LCSC
2 | 4.7kΩ | R2,R3 | R0201 | 4.7kΩ | RC0201JR-074K7L | YAGEO(国巨) | C142008 | LCSC
1 | 33Ω | R5 | R0201 | 33Ω | 0201WMJ0330TEE | UNI-ROYAL(厚声) | C423356 | LCSC
1 | 10kΩ | R6 | R0201 | 10kΩ | 0201WMF1002TEE | UNI-ROYAL(厚声) | C473048 | LCSC
1 | 249kΩ | R9 | R0201 | 249kΩ | RC0201FR-07249KL | YAGEO(国巨) | C273273 | LCSC
1 | TS-1928-B | SW1 | KEY-SMD_4P-L2.8-W2.0-P1.20-LS3.0-TL |  | TS-1928-B | XKB Connection(中国星坤) | C1121891 | LCSC
1 | OFF|ON | SW2 | SW-SMD_MSK12CO2 |  | MINI MSK12CO2 | SHOU HAN(首韩) | C2681570 | LCSC
1 | CH591D | U1 | QFN-20_L3.0-W3.0-P0.40-BL-EP1.7 |  | CH591D | WCH(南京沁恒) | C20606919 | LCSC
1 | TCA9406DCUR | U3 | VSSOP-8_L2.3-W2.0-P0.50-LS3.1-BL |  | TCA9406DCUR | TI(德州仪器) | C840107 | LCSC
1 | JTD6206S-3.0V | U4 | SOT-23-3_L2.9-W1.3-P1.90-LS2.4-BR |  | JTD6206S-3.0V | JTD(晶泰达) | C49308288 | LCSC
1 | XC6206P182MR | U5 | SOT-23-3_L3.0-W1.7-P0.95-LS2.9-BR |  | XC6206P182MR | UMW(友台半导体) | C347373 | LCSC
1 | BMI270 | U6 | LGA-14_L3.0-W2.5-P0.50-BR |  | BMI270 | Bosch(博世) | C2836813 | LCSC
1 | MAX86916EFD+T | U7 | SENSORS-SMD_L7.0-W3.5_MAX86916EFD |  | MAX86916EFD+T | ADI(亚德诺)/MAXIM(美信) | C3178277 | LCSC
1 | SSP8099-50YT | U8 | TDFN-6_L2.0-W2.0-P0.65-BL-EP |  | SSP8099-50YT | Siproin(上海矽朋) | C7424767 | LCSC
1 | 32MHz | X1 | CRYSTAL-SMD_4P-L3.2-W2.5-BL | 32MHz | X322532MOB4SI | YXC(扬兴晶振) | C9009 | LCSC

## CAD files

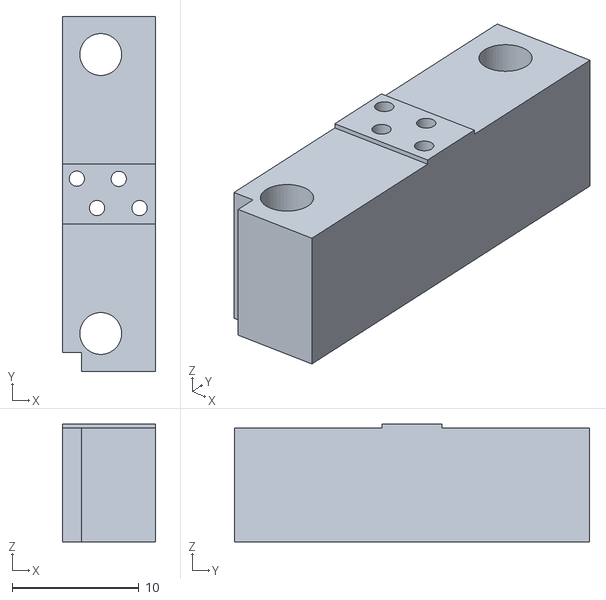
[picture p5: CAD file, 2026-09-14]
NewBoard/Programming_Jig/pogo_jig_top.stl
7.30 x 28.0 x 9.30

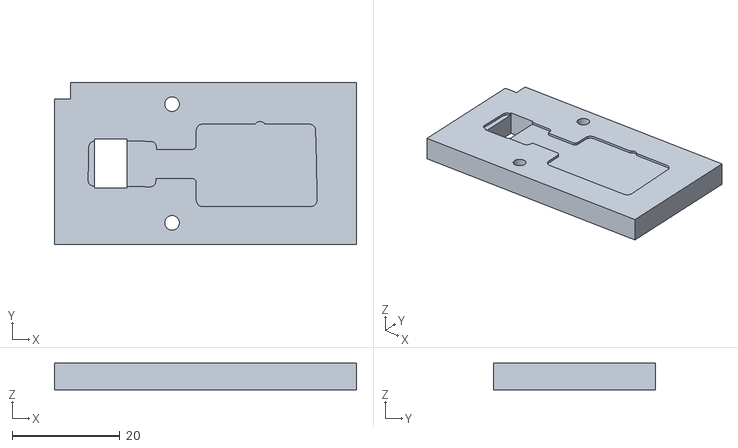
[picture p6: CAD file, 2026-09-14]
NewBoard/Programming_Jig/pogo_jig_base.stl
56.0 x 30.0 x 5.00

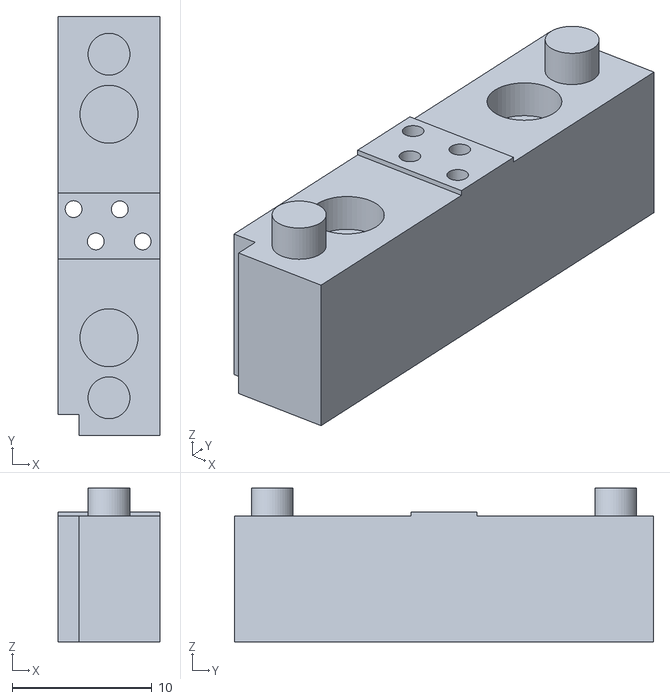
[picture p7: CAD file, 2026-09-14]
NewBoard/Programming_Jig/pogo_jig_top_mag.stl
7.30 x 30.0 x 11.0

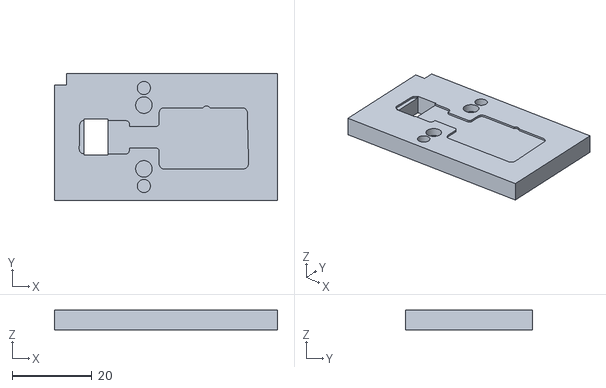
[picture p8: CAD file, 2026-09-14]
NewBoard/Programming_Jig/pogo_jig_base_mag.stl
56.0 x 32.0 x 5.00

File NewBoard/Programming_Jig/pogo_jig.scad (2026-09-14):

// Pogo-pin programming jig for the Animal Pulse Sensing flex board (CH591D).
// Coordinates = EasyEDA pick-and-place frame (mm). Pad centres measured from the board render (+/-0.05 mm):
//   5V [-6.086, -1.21], GND [-4.496, 1.105], D- [-2.779, -1.192], D+ [-1.139, 1.108]   pad dia 2.15 mm
// If you confirm different numbers in EasyEDA, just edit `pads` below and re-render.
$fn=48;
pads=[[-6.086,-1.210],[-4.496,1.105],[-2.779,-1.192],[-1.139,1.108]];                 // order: 5V, GND, D-, D+
pin_hole_d=1.2;   // 1.2 = press-fit P75 pogo pin (1.02 mm barrel) + CA glue; 1.4 for R75 receptacles
flex_t=0.25; pocket_depth=0.5; pocket_clear=0.2;
base_t=5.0; base_x=[-26.0,30.0]; base_y=[-16.0,16.0];
sensor_slot=[-18.6,-12.6,-4.5,4.5];   // through-slot under the MAX86916 (mounted on the bottom side of the head)
top_x=[-7.20,0.10]; top_y=[-15.0,15.0]; top_h=9.0;
magnetic=true;   // true: magnets + pegs (no screws). false: M3 screw version
mag_hole_d=4.15; mag_depth=2.1; mag_y=8.0;      // N52 disc magnets 4 x 2 mm (Amazon B0D6BCJCP7), 2 in base + 2 in carrier. Use mag_depth=3.1 for 4 x 3 mm discs
peg_d=3.0; peg_h=2.0; peg_y=12.3; peg_hole_d=3.3; peg_hole_depth=2.5;
tongue_w=4.7; bolt_x=-4.2; bolt_y=11.0; bolt_clear_d=3.3; bolt_tap_d=2.7;
outline=[[12.121,7.613],[12.556,7.505],[12.755,7.342],[12.882,7.142],[21.248,7.142],[21.719,6.997],[22.135,6.581],[22.244,6.183],[22.244,4.589],[22.280,4.553],[22.280,3.213],[22.317,3.176],[22.317,1.728],[22.353,1.691],[22.353,-0.156],[22.389,-0.192],[22.389,-2.039],[22.425,-2.075],[22.425,-2.981],[22.461,-3.017],[22.461,-5.299],[22.498,-5.335],[22.498,-6.748],[22.534,-6.784],[22.389,-7.291],[22.009,-7.671],[21.610,-7.780],[15.417,-7.780],[15.381,-7.816],[1.436,-7.816],[1.219,-7.780],[0.966,-7.671],[0.766,-7.508],[0.513,-7.037],[0.477,-6.820],[0.477,-3.307],[0.440,-3.162],[0.169,-2.818],[-0.266,-2.601],[-0.302,-2.637],[-0.338,-2.601],[-7.329,-2.601],[-7.383,-2.800],[-7.383,-3.307],[-7.491,-3.705],[-7.799,-4.013],[-8.198,-4.122],[-9.139,-4.122],[-9.176,-4.085],[-18.303,-4.085],[-19.100,-3.904],[-19.353,-3.723],[-19.516,-3.488],[-19.589,-3.162],[-19.589,-2.293],[-19.552,-2.256],[-19.480,3.032],[-19.335,3.502],[-19.136,3.738],[-18.919,3.883],[-18.484,3.991],[-8.125,3.919],[-7.727,3.810],[-7.419,3.502],[-7.310,3.104],[-7.329,2.434],[-0.338,2.434],[0.096,2.615],[0.296,2.814],[0.477,3.176],[0.477,6.183],[0.622,6.653],[0.821,6.889],[1.038,7.034],[1.473,7.142],[11.397,7.142],[11.523,7.342],[11.723,7.505],[12.121,7.613]];

module rbox(x0,x1,y0,y1,z0,z1) translate([x0,y0,z0]) cube([x1-x0,y1-y0,z1-z0]);
module base() difference() {
  rbox(base_x[0],base_x[1],base_y[0],base_y[1],0,base_t);
  translate([0,0,base_t-pocket_depth]) linear_extrude(pocket_depth+1) offset(r=pocket_clear) polygon(outline);
  rbox(sensor_slot[0],sensor_slot[1],sensor_slot[2],sensor_slot[3],-1,base_t+1);
  if(!magnetic) for(s=[-1,1]) translate([bolt_x,s*bolt_y,-1]) cylinder(d=bolt_tap_d,h=base_t+2);
  if(magnetic) for(s=[-1,1]) { translate([(top_x[0]+top_x[1])/2,s*mag_y,base_t-mag_depth]) cylinder(d=mag_hole_d,h=mag_depth+1);
                                translate([(top_x[0]+top_x[1])/2,s*peg_y,base_t-peg_hole_depth]) cylinder(d=peg_hole_d,h=peg_hole_depth+1); }
  rbox(base_x[0]-1,base_x[0]+3,base_y[1]-3,base_y[1]+1,-1,base_t+1);   // orientation key (corner notch)
}
module top() { z_floor=base_t-pocket_depth; z_tongue=z_floor+flex_t-0.05;
  difference() {
    union() { rbox(top_x[0],top_x[1],top_y[0],top_y[1],base_t,base_t+top_h);
              rbox(top_x[0],top_x[1],-tongue_w/2,tongue_w/2,z_tongue,base_t+0.01);
              if(magnetic) for(s=[-1,1]) translate([(top_x[0]+top_x[1])/2,s*peg_y,base_t-peg_h]) cylinder(d=peg_d,h=peg_h+0.01); }
    for(p=pads) translate([p[0],p[1],base_t-2]) cylinder(d=pin_hole_d,h=top_h+3);
    if(!magnetic) for(s=[-1,1]) translate([bolt_x,s*bolt_y,base_t-2]) cylinder(d=bolt_clear_d,h=top_h+3);
    if(magnetic) for(s=[-1,1]) translate([(top_x[0]+top_x[1])/2,s*mag_y,base_t-1]) cylinder(d=mag_hole_d,h=mag_depth+1);
    rbox(top_x[0]-1,top_x[0]+1.5,top_y[1]-1.5,top_y[1]+1,base_t-2,base_t+top_h+1);      // orientation key
  } }
// Assembly view (top sits on base). For printing export each part separately; print the top block tongue-side up (flip 180 deg).
base();
top();

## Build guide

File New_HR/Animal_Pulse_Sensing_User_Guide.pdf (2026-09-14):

Animal Pulse Sensing — User Guide

# ANIMAL PULSE SENSING

# User Guide

Flexible Animal Pulse-Sensing Hardware

## Contents

## 1. Introduction

The Animal Pulse Sensing board is a flexible, battery-powered embedded sensing platform designed to acquire pulse-related sensor data and motion information using a compact microcontroller-based architecture. The hardware integrates the CH591D microcontroller, MAX86916 sensing device, BMI270 inertial sensor, multiple regulated supply rails, a USB data/debug interface, and basic status indication.

This guide is written for a non-specialist technical user. It focuses on how the board is powered, connected, programmed, and operated, rather than providing a component-by-component circuit design review.

The hardware description is based on the supplied project schematic. Firmware-dependent behavior and information not established by the schematic are identified as such rather than being presented as fixed hardware requirements.

## 2. System Overview

The board operates from a single rechargeable battery input in the 3.6 V to 4.2 V range. Power is controlled by the ON/OFF section and distributed to the regulated supply sections. The CH591D is the main controller and communicates with the sensing devices. A logic shifter provides voltage-domain translation where required.

- CH591D main microcontroller and system controller.
- MAX86916 pulse/optical sensing subsystem; this guide covers its supply and I²C interface only.
- BMI270 inertial sensing subsystem; this guide covers its supply and digital interface only.
- 3 V regulator regulated 3 V supply for the main digital domain.
- 1.8 V LDO regulated low-voltage rail.
- 5 V step-up converter generates the 5 V rail shown in the schematic.
- Logic shifter translates digital signals between applicable voltage domains.
- 32 MHz crystal external clock reference shown for the CH591D.
- Battery and ON/OFF circuitry portable power source and system power control.
- Debugging pads expose 5 V, GND, D+ and D− for programming/debugging.

## 3. Power Architecture

The board is designed around a single battery input. The required battery voltage range is 3.6 V to 4.2 V. The battery connects to the battery section and is controlled by the ON/OFF power switch before being used by the rest of the circuit.

- Battery input: 3.6–4.2 V.
- 3 V regulator: provides the regulated 3 V supply for the main digital system and associated circuitry.
- 1.8 V LDO: provides the regulated 1.8 V rail for low-voltage circuitry.
- 5 V step-up: generates the 5 V rail shown in the schematic.
- Logic shifter: translates digital signals between the applicable logic-voltage domains.
- Switch the board OFF before connecting or disconnecting the battery.
Recommended power-up sequence:
1. Confirm the battery is within the 3.6–4.2 V requirement.
2. Confirm the ON/OFF switch is OFF.
3. Connect the battery with the correct polarity.
4. Turn the ON/OFF switch ON.
5. Allow the regulated rails to settle before beginning normal sensor operation or programming.

Power-down:

6. Stop active data acquisition or programming.
7. Turn the ON/OFF switch OFF.
8. Disconnect the battery if the board will be stored or transported.

## 4. Main Hardware Interfaces

### 4.1 CH591D Microcontroller

The CH591D is the main controller of the board. It interfaces with the sensing devices, controls the board's status indication, and provides the USB data/programming connection exposed on the debugging pads. A 32 MHz crystal is shown as the external clock source.

### 4.2 MAX86916 Interface

The MAX86916 section is connected to the board's regulated supply and digital communication network. The schematic shows local supply decoupling and I²C pull-up resistors. For normal operation, ensure the required supply rails are present and the I²C pull-ups are connected to the appropriate logic supply.

### 4.3 BMI270 Interface

The BMI270 is connected to the CH591D through the digital sensor interface shown in the schematic and has local supply decoupling. Sensor communication should remain within the logic-voltage domain established by the board.

### 4.4 Logic Shifter

The logic shifter translates digital signals between the voltage domains used by the connected devices. Its two supply sides are connected to the corresponding rails shown on the schematic.

### 4.5 Crystal / Clock

A 32 MHz crystal is connected to the CH591D clock pins with associated capacitors to ground. Avoid unnecessary probing or loading of these clock nodes during normal operation.

## 6. Signal / Pin Description

The following is a practical user-facing signal summary. It is not intended to replace the full CH591D pinout.

Signal / Net | Function | Typical Connection / Use | Notes
VBAT / BAT+ | Battery input | 3.6–4.2 V battery | Observe polarity.
SW_PWR | Switched power | Output of ON/OFF power path | Present when board is ON.
3 V | Regulated supply | Main digital domain | Verify before sensor operation.
1.8 V | Regulated supply | Low-voltage domain | Used by applicable circuitry.
5 V | Boosted supply | 5 V domain / programming reference | Do not short to other rails.
SDA | I²C data | MCU ↔ sensor devices | Logic shifter already added
SCL | I²C clock | MCU ↔ sensor devices | Logic shifter already added.
D+ | USB data + | Programming/debugging | Connect to USB host D+.
D− | USB data − | Programming/debugging | Connect to USB host D−.
GND | Ground reference | Battery / USB / measurement reference | Common circuit reference.
ANT | RF/antenna connection | CH591D RF section | Keep as designed.

## 7. Board Layout Reference

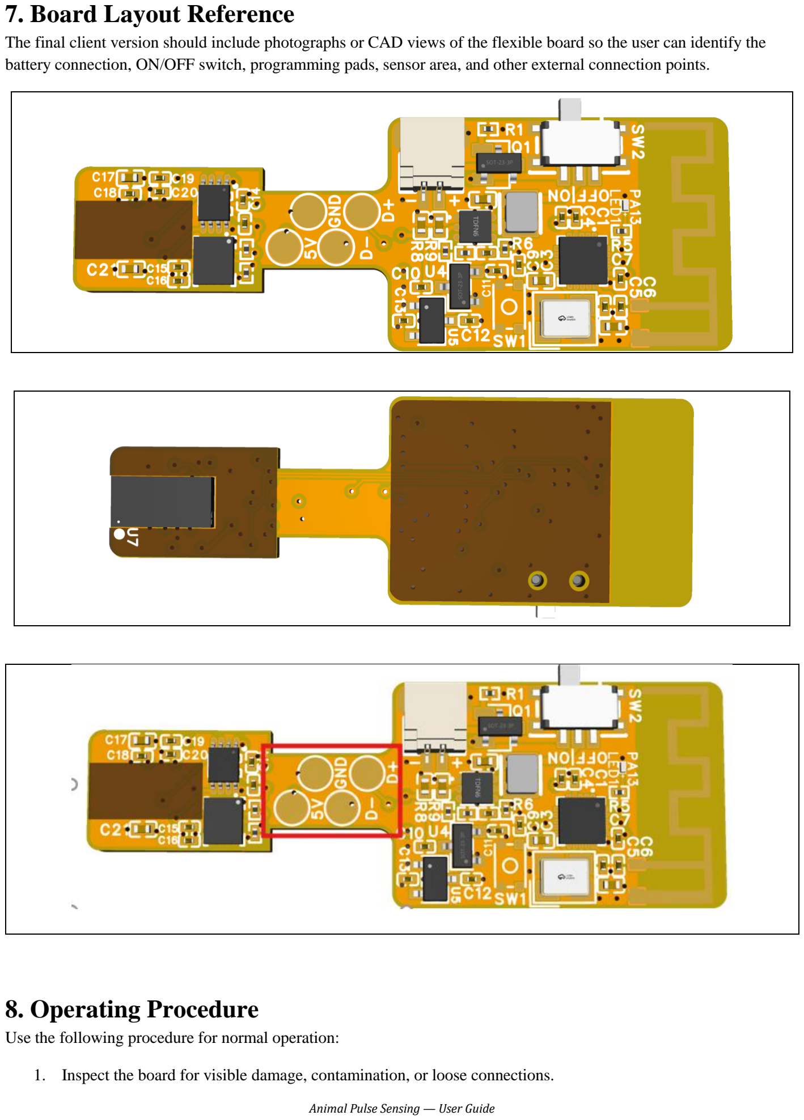
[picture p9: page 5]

The final client version should include photographs or CAD views of the flexible board so the user can identify the battery connection, ON/OFF switch, programming pads, sensor area, and other external connection points.

## 8. Operating Procedure

Use the following procedure for normal operation:

1. Inspect the board for visible damage, contamination, or loose connections.

2. Confirm that the battery voltage is between 3.6 V and 4.2 V.
3. Make sure the ON/OFF switch is OFF.
4. Connect the battery with correct polarity.
5. Turn the ON/OFF switch ON.
6. Verify that the board powers up normally. If required, the 3 V, 1.8 V and 5 V rails can be checked with a multimeter.
7. Allow the CH591D firmware to initialize the sensor interfaces.
8. Operate the board according to the application's data-acquisition procedure.
9. When finished, stop application activity and switch the board OFF.
10. Sampling rate, data format, LED behavior, and application-level processing are firmware-dependent and are not fixed by the supplied schematic.

## 9. Programming and Debugging Using D+ / D−

The schematic provides a dedicated debugging pad group labelled 5 V, D+, D− and GND. These pads expose the USB data connection of the CH591D and provide a convenient connection point to a USB host for programming/debugging.

### 9.1 Pad Identification

Pad | Purpose
5 V | USB/programming power reference or board 5 V rail, depending on the programming setup.
GND | Ground/reference connection to the USB host or programmer.
D+ | USB positive data line.
D− | USB negative data line.

### 9.2 Programming Connection

- Disconnect and remove the battery from the board.
- Switch the board OFF before making programming connections.
- Connect the USB host/programmer ground to the board GND pad.
- Connect USB D+ to the board D+ pad.
- Connect USB D− to the board D− pad.
- Connect programming power as required by the chosen programming method. If USB 5 V is used to power the board, do not simultaneously connect the battery unless the power-path design explicitly permits simultaneous sources.
- Place the CH591D into the programming/bootloader mode required by the installed firmware and programming environment.
- Start the appropriate CH591D programming tool on the host computer and select the detected USB device, if applicable.
- Program the firmware and verify that the operation completes successfully.
- After programming, disconnect the programming setup or leave it connected for debugging as required.
- Return the board to normal battery-powered operation.

### 9.3 Debugging

For debugging, use D+, D− and GND and keep the board supply within the intended power range. If the USB connection is not detected, first check D+/D− orientation, GND continuity, board power, and whether the installed firmware/bootloader supports the intended USB programming method.

Note: the supplied schematic identifies the physical USB data pads but does not specify the exact host-side programming software, bootloader entry sequence, or firmware tool settings. These items should be finalized from the CH591D programming documentation and the project's firmware procedure.

## 10. LED Indication

The schematic includes an LED connected to an MCU-controlled signal. It can therefore be used by firmware as a status indicator. The exact meaning of steady, flashing, or off states should be defined by the firmware documentation.

## 11. Safety and Handling

Use only a battery within the specified 3.6–4.2 V range and observe correct polarity. Do not short the battery or power rails, and avoid connecting or disconnecting programming power while another power source is active unless the power-path arrangement has been verified. Protect the flexible board from excessive bending, ESD, moisture, and mechanical damage.

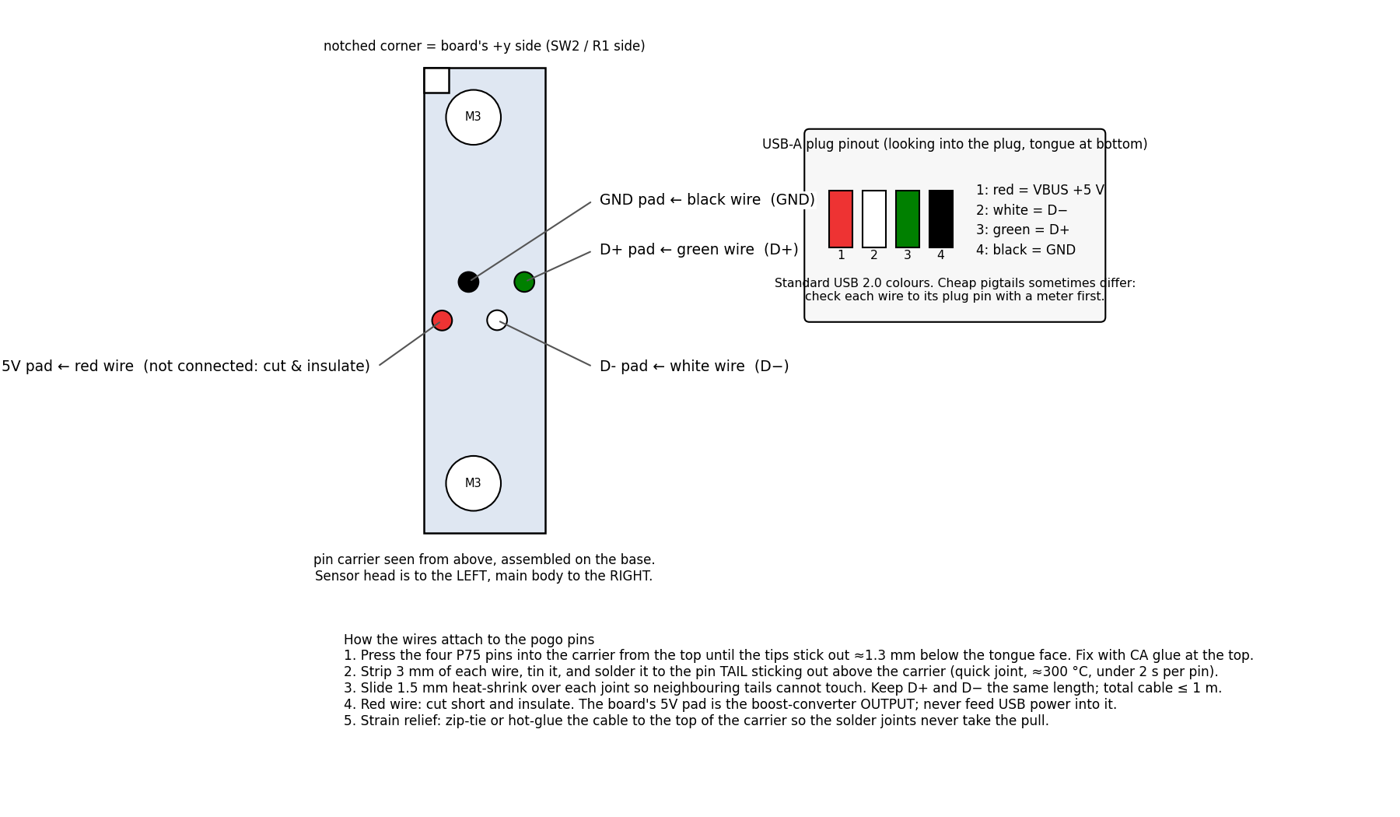
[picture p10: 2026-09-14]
NewBoard/Programming_Jig/jig_wiring.png

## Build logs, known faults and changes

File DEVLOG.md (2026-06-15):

# ESP32-S3 + MAX30102 Health Monitor — Development Log

End-to-end build log of a wireless fingertip/tail pulse-oximeter intended for
MATLAB / MonkeyLogic behavioral-recording setups (incl. marmoset task work).

---

## Hardware

- **MCU**: ESP32-S3-MINI-1 (rev v0.2), 8 MB embedded flash
  - Old PCB MAC: `90:70:69:2a:d8:2c`
  - New PCB MAC: `90:70:69:2a:d8:00`
- **Sensor**: MAX30102 (pulse oximetry, IR + Red LEDs)
- **Charging**: TP4056 + USB-C, 1 A charge current (R9 = 1.2 kΩ)
- **Battery**: 3.7 V LiPo via JST-PH connector
- **Power path**: USB → TP4056 → BAT+ → SW3 → SWITCH rail → regulators → ESP32
  (single SWITCH rail powers everything; SW3 must be ON for either USB or battery to power the chip)
- **Buttons**: SW1 = BOOT (right, IO0), SW2 = ENABLE / RESET (left, CHIP_PU)
- **TP4056 status pins** (open-drain, active LOW):
  - IO7 = CHRG# (LOW while charging)
  - IO6 = STDBY# (LOW when charge complete)
- **Indicator LED**: IO5 + 220 Ω
- **Sensor I²C**: SDA = IO9, SCL = IO8

### Pin map

| ESP32 GPIO | Schematic label | Function |
|---|---|---|
| GPIO0  | IO0 / BOOT  | BOOT strap, SW1 |
| GPIO4  | IO4 / INT | MAX30102 interrupt |
| GPIO5  | IO5 / LED | Indicator LED |
| GPIO6  | IO6 / FULL  | TP4056 STDBY# |
| GPIO7  | IO7 / CHARGE | TP4056 CHRG# |
| GPIO8  | IO8 / SCL | I²C clock to MAX30102 |
| GPIO9  | IO9 / SDA | I²C data to MAX30102 |

---

## Software evolution

Five firmware iterations, all in `ESP32_HealthMonitor.ino`. Latest source on disk is **v6 (BLE + motion rejection)**; latest *flashed* is **v5**.

| Ver | Transport | Notes |
|----|---|---|
| v1 | WiFi STA (MIT) | Blocked by MIT subnet routing between WiFi 10.29.x.x and Ethernet 10.93.x.x |
| v2 | WiFi AP "HealthMonitor" + UDP broadcast 192.168.4.255:12345 @ 1 Hz | First working wireless path |
| v3 | WiFi AP + UDP @ 2.5 Hz, `beatAvg` HR, on-demand sampling via UDP `START`/`STOP` | Sensor LEDs only on while requested |
| v4 | v3 + `CHARGE=` field from TP4056 status pins | Top-bar shows Charging / Full / On battery |
| v5 | **BLE GATT** (custom service), same data fields | ~10× lower power than WiFi AP |
| v6 (on disk, not flashed) | v5 + motion-resilient HR + Human/Marmoset profile + PI + HRV + skin temp | Blocked: SW1 BOOT button defective on current PCB |

---

## Current architecture (v5 firmware, current GUI)

```
ESP32-S3 ──BLE GATT──► Windows laptop ──LSL outlet──► MonkeyLogic LSL inlet
  • MAX30102                    ▲                       (auto-discovers stream)
  • TP4056 status pins          │
  • 2.5 Hz notify               │ Python tkinter GUI
                                │   • Sensor on/off button
  (writes "START"/"STOP" ──BLE──┤   • Live View / Record mode
                                │   • CSV logger
                                └── • LSL streamer (pylsl)
```

### BLE GATT service

- **Service UUID**: `12345678-1234-1234-1234-123456789abc`
- **DATA characteristic** (NOTIFY): `12345678-1234-1234-1234-123456789abd`
  - ASCII status string sent at 2.5 Hz
- **CMD characteristic** (WRITE): `12345678-1234-1234-1234-123456789abe`
  - Accepts `"START"`, `"STOP"`, and (v6 only) `"SPECIES:HUMAN"` / `"SPECIES:MARMOSET"`

### Status packet format

v5 (currently running):
```
SAMPLING=1,HR=83,SPO2=98,AVG=82,VALID=1,CHARGE=charging
SAMPLING=1,HR=-1,SPO2=-1,AVG=0,VALID=0,WARMUP=42,CHARGE=battery
SAMPLING=0,HR=-1,SPO2=-1,AVG=0,VALID=0,CHARGE=full
SENSOR=error,CHARGE=battery        # I²C bus to MAX30102 failed
```

v6 (in source, awaiting flash):
```
SAMPLING=1,HR=83,SPO2=98,AVG=82,VALID=1,PI=2.4,TEMP=33.5,HRV=38,
  SPECIES=human,CHARGE=charging
```

---

## Key technical findings

### 1. CDC on Boot kills the WiFi AP
On the WiFi-era firmware, building with `-DARDUINO_USB_CDC_ON_BOOT=1` (FQBN variant `esp32s3:CDCOnBoot=cdc`) made the `HealthMonitor` softAP invisible to laptops. Verified twice. The default FQBN (`esp32:esp32:esp32s3`) keeps the AP visible but loses the soft-reset upload path → manual BOOT button required for every flash.

Made irrelevant by the BLE switch in v5 — no WiFi at all anymore.

### 2. HR algorithm produced harmonic doubling
The MAX30105 library's `maxim_heart_rate_and_oxygen_saturation()` periodically reports 2× the real HR (e.g., 166 instead of 83). Even `checkForBeat()` does this — it detects the secondary dicrotic-notch peak as a separate beat. **Solution (v6)**: enforce a refractory period after each detected beat (300 ms human / 100 ms marmoset). Single drop-in fix.

### 3. TP4056 can never report "Full" on this design
The load (ESP32 ~120 mA on WiFi, ~15 mA on BLE) sits on the **BAT+ rail**, not behind a separate OUT pin. The TP4056's charge-complete logic waits for current to drop below ~100 mA → never fires while WiFi is on (load > threshold). With BLE the idle load is below threshold so `STDBY#` should fire and we should finally see `CHARGE=full`.

### 4. BLE is ~10× lower power than WiFi AP
Measured-out runtime: this device on WiFi died in ~1 minute on a half-charged cell. On BLE with sensor on, same cell ran a 20-minute (3105-row) recording successfully. BLE idle draw is ~10-20 mA vs ~120 mA for WiFi AP.

### 5. MAX30102 I²C state machine can wedge on brown-out
After repeated battery brown-outs, the MAX30102 may stop responding to `sensor.begin()`. **Fix in firmware**: don't lock up in the failure path — set `sensorOk = false`, keep BLE alive, send `SENSOR=error` so the GUI can show the failure instead of going dark. **Fix in hardware**: full power cycle (disconnect both USB and battery JST for 60 s) to drain the sensor's local caps.

### 6. Battery state is impossible to monitor without a hardware mod
The schematic has no ADC divider from BAT+ to a free GPIO. The only "battery info" we can read is the TP4056's two open-drain status pins (charging / full / battery). True voltage / percentage requires soldering a 2× 100 kΩ divider from BAT+ to a free ADC pin (e.g., GPIO1).

### 7. SW1 (BOOT button) on the current PCB is unreliable
After v5 was flashed on the current PCB, SW1 stopped reliably pulling IO0 LOW. Multiple BOOT+RESET sequences with 30+ esptool retries all failed to enter ROM bootloader mode. Likely a cold solder joint or worn-out switch contact. Workarounds documented below.

---

## Build & flash workflow

### Compile (no CDC on Boot)

```powershell
$ardc = "$env:TEMP\arduino-cli-bin\arduino-cli.exe"
& $ardc compile `
  --fqbn "esp32:esp32:esp32s3" `
  --output-dir "C:\Users\Owner\AppData\Local\Temp\esp32build_hm_v6" `
  "...\Documents\Arduino\ESP32_HealthMonitor"
```

`arduino-cli.exe` needs to be downloaded per-session; cached to `$env:TEMP\arduino-cli-bin`. Quick install:
```powershell
Invoke-WebRequest https://downloads.arduino.cc/arduino-cli/arduino-cli_latest_Windows_64bit.zip -OutFile $env:TEMP\arduino-cli.zip
Expand-Archive $env:TEMP\arduino-cli.zip $env:TEMP\arduino-cli-bin -Force
```

### Flash (BOOT-button entry to bootloader, when SW1 works)

1. Hold BOOT (SW1, right) — keep holding firmly with a pen tip
2. Briefly tap RESET (SW2, left)
3. Keep holding BOOT for 5-10 s
4. Run esptool:
   ```powershell
   $esptool = "C:\Users\Owner\AppData\Local\Arduino15\packages\esp32\tools\esptool_py\5.2.0\esptool.exe"
   & $esptool --chip esp32s3 --port COM<N> --baud 921600 `
     --before no-reset --after hard-reset `
     write-flash -z 0x0 "<path>\ESP32_HealthMonitor.ino.merged.bin"
   ```
5. After flashing, **manually press RESET** to start the new firmware (the RTS-pin "hard reset" in esptool is a no-op on this board — no auto-reset circuit).

### Flash fallback when SW1 is unreliable

#### A) Paperclip / tweezer jumper across SW1 pads
The fastest workaround with no soldering. SW1 is a 4-pin SMD tactile switch. Two of the four pins are connected to GND, the other two are connected to IO0 via a 10 kΩ pull-up (R1) and a 100 nF debounce cap (C1). Pressing the button shorts IO0 to GND.

To simulate the press without a working switch:
1. Locate SW1 on the PCB (the right-side button)
2. With a fine metal tweezers tip or paperclip end, **bridge two diagonal pads** of SW1 — touch one pad and an adjacent diagonal pad simultaneously
3. While the jumper is held, briefly press SW2 (RESET / ENABLE) with another finger
4. Release SW2 — keep the SW1 jumper held for 2 more seconds
5. Remove the jumper
6. The chip is now in ROM bootloader. Immediately run esptool:
   ```powershell
   $esptool = "C:\Users\Owner\AppData\Local\Arduino15\packages\esp32\tools\esptool_py\5.2.0\esptool.exe"
   & $esptool --chip esp32s3 --port COM<N> --baud 921600 `
     --before no-reset --after hard-reset `
     write-flash -z 0x0 "C:\Users\Owner\AppData\Local\Temp\esp32build_hm_v6\ESP32_HealthMonitor.ino.merged.bin"
   ```
7. After flashing, briefly tap SW2 (RESET) to start the new firmware.

Pro tip: tape a piece of foil between two SW1 pads if you want a hands-free "stuck on" while you tap RESET with the same hand.

#### B) Resolder or replace SW1
Permanent fix. ~15 min with a fine-tip soldering iron.

1. Heat each pad of the existing SW1 in turn while gently lifting with tweezers to remove
2. Clean residual solder with desoldering braid
3. Apply small dot of flux to each pad
4. Place a new 4-pin SMD tactile switch (e.g., C&K PTS645 series, ~6×6 mm) in the same orientation
5. Solder each leg
6. Test continuity: multimeter between IO0 pad and GND should show open circuit normally, shorted when switch pressed

#### C) OpenOCD via JTAG (no buttons at all)
ESP32-S3 has a built-in USB-Serial/JTAG interface (the same `303A:1001` device that appears as a COM port). OpenOCD can flash via the JTAG side of that interface without using SW1 at all.

**Windows-specific setup** (one-time, ~30 min):
1. Download Zadig from https://zadig.akeo.ie/
2. With the board plugged in, open Zadig → Options → "List All Devices"
3. Find the entry labeled `USB JTAG/serial debug unit (Interface 2)` or similar — **NOT** the COM-port interface (Interface 0), only the JTAG one
4. From the driver dropdown, pick **WinUSB** (or **libusbK**)
5. Click "Replace Driver" — accept warnings
6. The COM port should still work (Interface 0 keeps its serial driver)
7. OpenOCD is already installed at `C:\Users\Owner\AppData\Local\Arduino15\packages\esp32\tools\openocd-esp32\v0.12.0-esp32-20251215\bin\openocd.exe`

**Flash command** (after Zadig setup):
```powershell
$openocd = "C:\Users\Owner\AppData\Local\Arduino15\packages\esp32\tools\openocd-esp32\v0.12.0-esp32-20251215\bin\openocd.exe"
$scripts = "C:\Users\Owner\AppData\Local\Arduino15\packages\esp32\tools\openocd-esp32\v0.12.0-esp32-20251215\share\openocd\scripts"
$bin = "C:\Users\Owner\AppData\Local\Temp\esp32build_hm_v6\ESP32_HealthMonitor.ino.merged.bin"

& $openocd -s $scripts -f "board/esp32s3-builtin.cfg" `
  -c "program_esp `"$bin`" 0x0 verify reset exit"
```

If you see `libusb_open() failed with LIBUSB_ERROR_NOT_FOUND` it means Zadig didn't install WinUSB on the right interface — redo step 3 (it must be the *JTAG* interface, not the COM-port one).

---

## Python GUI

Single tkinter window, ~600 lines. Background thread holds a `bleak` asyncio loop for BLE; main thread does UI + CSV + LSL.

### Features

- **BLE link**: scans for `HealthMonitor`, connects, subscribes to DATA notifications, reconnects on drop
- **Top bar**: connection status, BLE name, LSL stream name, power indicator (🔌/✅/🔋)
- **Sensor power button**: sends `START`/`STOP` over CMD characteristic
- **Big HR / SpO₂ readouts**
- **Auxiliary metric boxes** (PI, Temp, HRV, Species — populated when v6 firmware is flashed)
- **Profile toggle**: Human / Marmoset (sends `SPECIES:` command, v6 only)
- **Live View vs Record** mode buttons; Record opens save dialog and writes CSV
- **LSL outlet**: 8-channel float32 at 2.5 Hz, name `HealthMonitor`, type `Physiological`. Auto-broadcasts when GUI launches.
- **Clean shutdown**: on window close, sends STOP, closes BLE, flushes CSV

### Dependencies (miniconda base env)

```powershell
& "C:\Users\Owner\miniconda3\python.exe" -m pip install bleak pylsl
```

### CSV columns

```
timestamp_iso, epoch_s, hr_bpm, spo2_pct, hr_avg_bpm, valid,
pi_pct, temp_c, hrv_ms, species, charge_state
```

(v5 firmware leaves `pi_pct`, `temp_c`, `hrv_ms`, `species` empty; v6 fills them.)

### LSL channels

| # | Label | Unit | Notes |
|---|---|---|---|
| 1 | HR | bpm  | -1 when invalid/no finger |
| 2 | SpO2 | % | -1 when invalid |
| 3 | HR_avg | bpm  | rolling 8-beat average |
| 4 | Valid  | bool | gated by PI + finger detection |
| 5 | PI | % | perfusion index (v6 only) |
| 6 | Temp | °C | skin temp from MAX30102 (v6 only) |
| 7 | HRV | ms | RMSSD over last 8 beats (v6 only) |
| 8 | Charge | code | 0=battery, 1=charging, 2=full, -2=fault, -1=unknown |

---

## MonkeyLogic integration (LSL)

1. Launch GUI → outlet starts automatically. Green `LSL: HealthMonitor` indicator in the top bar confirms it's broadcasting.
2. In MonkeyLogic: `Other device settings → Lab Streaming Layer` opens the Setup dialog.
3. In any Stream slot, the dropdown should auto-discover `HealthMonitor`. If not, type `HealthMonitor` in the Name field.
4. Buffer length: 360 s default is fine for typical sessions.
5. Done.

After that, MonkeyLogic shows `360 s, 1 stream(s) selected` and records the HR / SpO₂ samples into the `.bhv2` file alongside its other channels, time-synced via LSL's local-clock.

---

## Motion artifacts and marmoset use

PPG sensors fundamentally struggle with motion: any change in optical path length between LED and photodetector looks like a pulse. For awake marmoset tail recording:

### What v5 already does
- `beatAvg` instead of FFT-based HR (less prone to algorithm doubling)
- `VALID=0` when no finger / IR below threshold
- On-demand sampling so the sensor is off when not needed

### What v6 adds (compiled, not flashed)
- **Refractory period** in beat detection → eliminates dicrotic-notch doubling
- **Species profiles**:
  - HUMAN: 30-220 bpm, 300 ms refractory, ±30 bpm/s outlier limit
  - MARMOSET: 150-400 bpm, 100 ms refractory, ±60 bpm/s outlier limit
- **Perfusion Index** (PI) — `(max−min)/mean` of IR signal over 4 s buffer
- **Outlier-rejecting median filter** on HR (5-sample)
- **HRV (RMSSD)** computed from inter-beat intervals
- **Skin temperature** from MAX30102 internal sensor
- `VALID=1` requires PI above species-specific threshold (gates noisy data automatically)

### Possible hardware additions for marmoset work
- **Accelerometer** (LIS3DH or MPU-6050) on the spare I²C lines — enables motion-gated VALID flag and motion-correlated subtraction
- **Battery voltage divider** (2 × 100 kΩ to GPIO1) for real charge %
- **Snug mounting clip** matters more than firmware — secure optical coupling cuts motion artifact by >50% on its own

---

## Battery diagnosis notes

The original PCB's cell shipped at near-zero voltage, likely deeply discharged in storage. Symptoms:
- Charged for 4+ hours on laptop USB → still died in <1 minute when unplugged
- Even 8 h overnight charge stored only ~2-3 mAh of usable capacity

The new PCB's cell is healthier — ran a 20-min BLE recording on battery alone.

### Testing a battery (multimeter)

```
Test 1 (resting, USB unplugged, wait 30 s):
  4.10 – 4.20 V  → fully charged
  3.80 – 4.10 V  → ~50-90 %
  3.30 – 3.80 V  → mostly empty
  < 3.0 V        → over-discharged, likely damaged
  ~ 0 V          → bad JST or dead cell

Test 2 (under load, USB unplugged, press RESET):
  Stays within ~0.1 V of resting  → healthy
  Sags by 0.3-0.5 V               → high internal resistance, degraded
  Crashes < 3 V                   → can't sustain load, replace

Test 3 (charging, USB plugged):
  Rising over time, 3.5-4.2 V     → healthy charge cycle
  Stuck at one value 30+ min      → cell not accepting charge
```

### Battery selection
For replacements: **JST-PH 2-pin, 3.7 V**, 300-500 mAh, dimensions ~25 × 35 mm (matches the existing footprint). Adafruit, SparkFun, or Amazon LiPo cells are fine.

### Estimated runtime (v5 BLE + healthy cell)
- Idle / Live View only: 10-20+ h
- Active sampling (LEDs on): 5-10 h
- Continuous recording: same 5-10 h

---

## File layout

```
Documents/Arduino/ESP32_HealthMonitor/
├── ESP32_HealthMonitor.ino      # firmware source (currently v6 on disk; v5 flashed)
├── health_monitor_gui.py        # Windows BLE + LSL + CSV GUI
├── health_monitor_receiver.m    # legacy MATLAB UDP receiver (for reference)
└── DEVLOG.md                    # this file
```

Compiled binaries (cached, only present after a successful build):
```
C:\Users\Owner\AppData\Local\Temp\esp32build_hm_ble\ESP32_HealthMonitor.ino.merged.bin   # v5
C:\Users\Owner\AppData\Local\Temp\esp32build_hm_v6\ESP32_HealthMonitor.ino.merged.bin    # v6 (awaiting flash)
```

---

## Open items / next steps

1. **Fix or bypass SW1** to enable v6 flash (resolder, jumper IO0→GND, or OpenOCD/JTAG with Zadig).
2. **Replace the original PCB's degraded LiPo** if returning to that hardware.
3. **Test v6 marmoset profile** on a calm animal — confirm HR range tracks correctly and PI gating reduces artifact.
4. **Optional hardware mods**: battery voltage divider; accelerometer on spare I²C.
5. **Document MonkeyLogic experiment script** that subscribes to the LSL stream and references HR/SpO₂ channels in trial logic.

---

## MRI safety

**This device is NOT MR-safe.** Do not bring it inside an MRI scan room.
- USB-C connector has ferromagnetic steel shell → projectile risk in high field
- LiPo cell foils heat under gradient pulses → burn risk
- 2.4 GHz BLE radio → severe RF interference with MRI imaging
- Multiple ICs have nickel-plated lead frames

For in-scanner pulse-ox, use a dedicated **fiber-optic MR-compatible** unit (Nonin 7500FO, Invivo Expression, etc.). The LSL framework from this project can subscribe to that device's stream and ours simultaneously for pre/in/post-scan continuity.

---

## Acknowledgements

ESP32 Arduino core 3.3.8 · SparkFun MAX30105 library 1.1.2 · NimBLE / Arduino BLE · `bleak` 3.0.2 · `pylsl` 1.18.2 · esptool 5.2.0 · arduino-cli 1.5.0

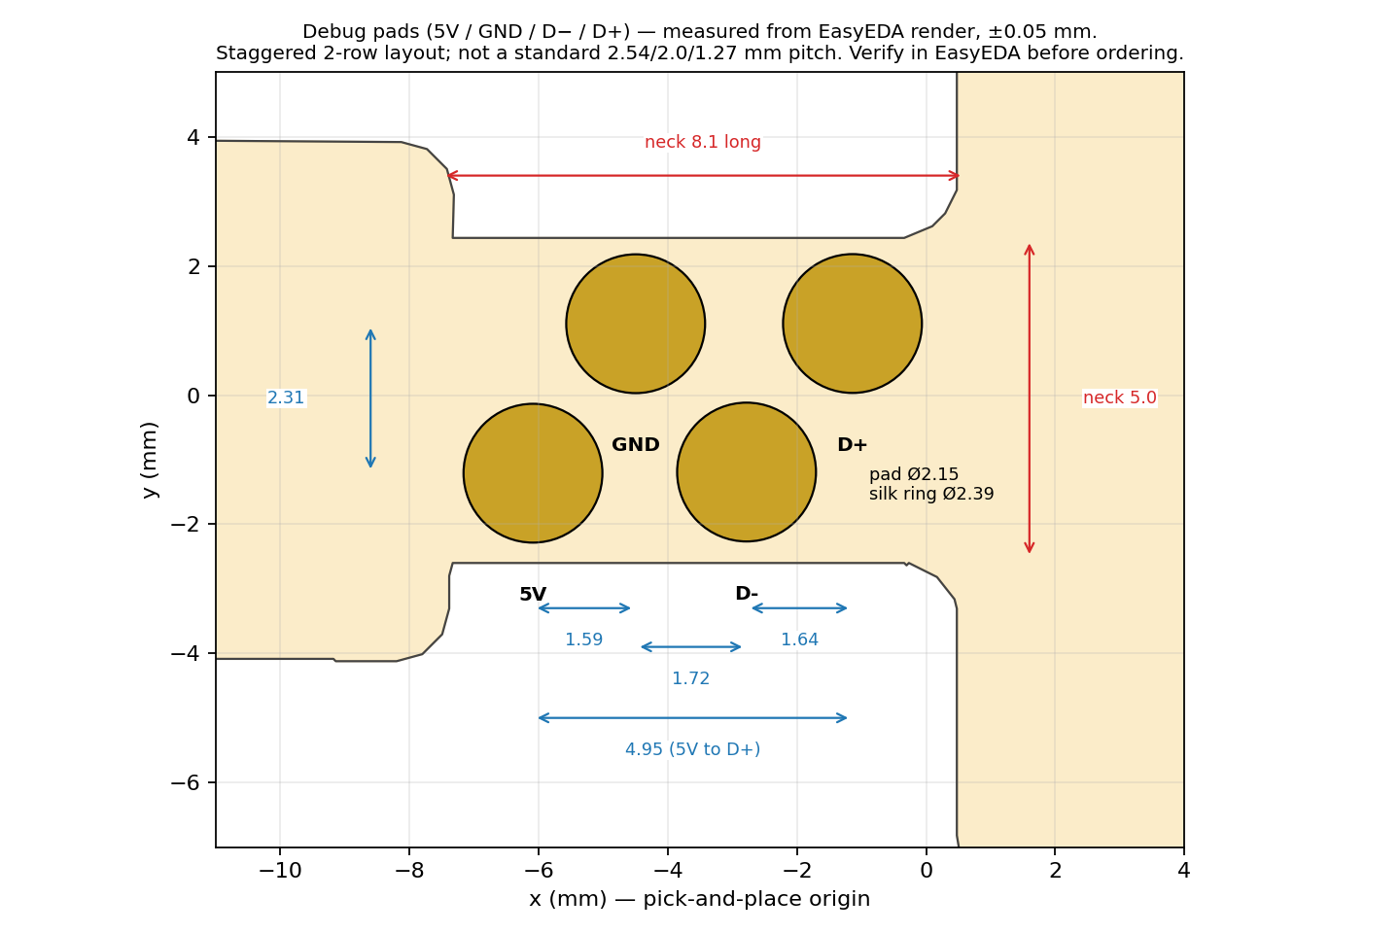
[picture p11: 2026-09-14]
NewBoard/Programming_Jig/debug_pad_layout.png

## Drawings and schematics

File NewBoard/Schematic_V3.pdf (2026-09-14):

# CH591D

# Crystal

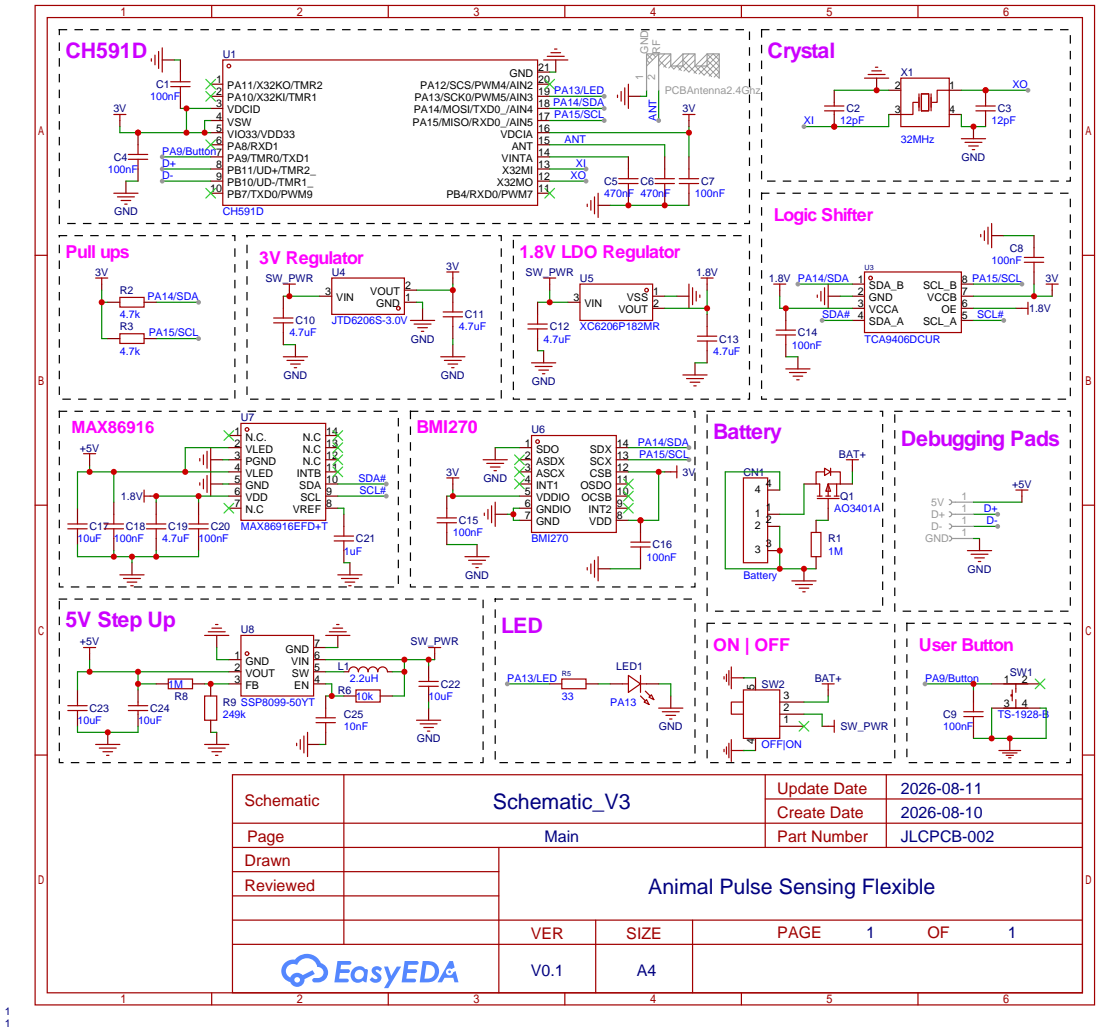
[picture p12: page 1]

OCSB 10 OSDO 11 CSB 12 SCX 13 SDX 14

Animal Pulse Sensing Flexible

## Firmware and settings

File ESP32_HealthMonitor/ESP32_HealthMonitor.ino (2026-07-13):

/*
 * ESP32-S3 + MAX30102 Health Monitor — BLE Edition (v6)
 *
 * Additions over v5:
 *   • Beat-detector refractory period — eliminates dicrotic-notch double-counting
 *   • Per-species profiles (HUMAN / MARMOSET) with different HR ranges
 *   • Perfusion Index (PI) for signal-quality scoring
 *   • Outlier rejection: HR jumps > maxRate are filtered to last-good value
 *   • Motion variance gating: VALID=0 when recent IR variance is too high
 *   • HRV (RMSSD over last 5 inter-beat intervals)
 *   • Skin temperature from MAX30102 internal sensor
 *
 * Custom GATT service exposes:
 *   DATA characteristic (NOTIFY)  — ASCII status string, e.g.:
 *     "SAMPLING=1,HR=83,SPO2=98,AVG=82,VALID=1,PI=2.4,
 *      TEMP=33.5,HRV=38,SPECIES=human,CHARGE=charging"
 *   RAW  characteristic (NOTIFY)  — BINARY raw-waveform batch (little-endian),
 *     cheaper to build and ~2x smaller than ASCII so the link sustains a
 *     higher sample rate. A host can re-derive HR/SpO2 or watch the PPG live.
 *     Layout (magic 0xA6 = v2, 3-byte samples; 0xA5 = legacy 4-byte):
 *       [0]  uint8   magic = 0xA6
 *       [1]  uint8   nSamples
 *       [2]  uint8   nBeats
 *       [3]  uint32  seq   (packet counter; host detects drops)
 *       [7]  uint32  t0    (real millis of first sample)
 *       [11] uint16  dt    (real avg sample spacing, ms)
 *       [13] uint24 * nSamples  IR   (18-bit ADC, low 3 bytes LE)
 *       ...  uint24 * nSamples  Red
 *       ...  uint32 * nBeats    beat timestamps (device millis, may be 0)
 *   CMD  characteristic (WRITE)   — accepts:
 *     "START" / "STOP"
 *     "SPECIES:HUMAN" / "SPECIES:MARMOSET"
 */

#include <Wire.h>
#include "MAX30105.h"
#include "heartRate.h"
#include "spo2_algorithm.h"
#include <BLEDevice.h>
#include <BLEServer.h>
#include <BLEUtils.h>
#include <BLE2902.h>
#include <math.h>

// ---- BLE identifiers ----
#define DEVICE_NAME     "HealthMonitor1"
#define SERVICE_UUID    "12345678-1234-1234-1234-123456789abc"
#define DATA_CHAR_UUID  "12345678-1234-1234-1234-123456789abd"
#define CMD_CHAR_UUID   "12345678-1234-1234-1234-123456789abe"
#define RAW_CHAR_UUID   "12345678-1234-1234-1234-123456789abf"

// ---- I2C ----
#define SDA_PIN 9
#define SCL_PIN 8

// ---- TP4056 charging status ----
#define PIN_CHRG   7
#define PIN_STDBY  6

// ---- Finger threshold ----
#define FINGER_THRESHOLD 50000UL

// ---- Species profile ---------------------------------------------------------
enum Species { SPECIES_HUMAN = 0, SPECIES_MARMOSET = 1 };

struct ProfileParams {
    int   hrMin;            // bpm
    int   hrMax;            // bpm
    int   refractoryMs;     // min interval between beats
    int   maxHrChangeBpm;   // per-second rate-of-change limit for outlier reject
    float piMinPct;         // perfusion-index gate
    const char* label;
};

const ProfileParams PROFILES[] = {
    /* HUMAN    */ {  30, 220, 300, 30, 0.5f, "human"    },
    /* MARMOSET */ { 150, 400, 100, 60, 0.4f, "marmoset" },
};

Species  species = SPECIES_HUMAN;
const ProfileParams& prof() { return PROFILES[(int)species]; }

// ---- HR rolling average (display) ----
const byte HR_SAMPLES = 8;
byte   rates[HR_SAMPLES];
byte   rateIndex      = 0;
long   lastBeat       = 0;
float  beatsPerMinute = 0;
int    beatAvg        = 0;

// ---- Inter-beat-interval buffer for HRV (RMSSD over last N) ----
const byte IBI_BUF = 8;
unsigned long ibis[IBI_BUF];     // milliseconds
byte ibiCount = 0;
byte ibiHead  = 0;

// ---- HR outlier-reject median filter (last 5 reported HR) ----
const byte HR_MEDIAN = 5;
int hrHistory[HR_MEDIAN];
byte hrHistCount = 0;
byte hrHistHead  = 0;
int  lastGoodHR  = -1;
unsigned long lastGoodHRTime = 0;

// ---- SpO2 buffers ----
#define SPO2_BUF_LEN       100
#define SAMPLES_PER_ITER   10
uint32_t irBuffer[SPO2_BUF_LEN];
uint32_t redBuffer[SPO2_BUF_LEN];
int32_t  spo2;
int8_t   validSPO2;
int32_t  hrFromAlgo;
int8_t   validHR;

// ---- Sampling state ----
bool sampling          = false;
int  samplesCollected  = 0;
bool sensorOk          = false;
bool deviceConnected   = false;

// SpO2 is computed on a slow cadence, NOT every cycle. The maxim algorithm is
// expensive (~hundreds of ms) and running it every loop was starving the beat
// detector — leaving the PPG blind ~0.6 s out of every 1 s. SpO2 changes slowly
// so 3 s is plenty, and the IR stream now feeds beat detection continuously.
unsigned long lastSpO2Calc = 0;
const unsigned long SPO2_INTERVAL_MS = 3000;

// HR / HRV are only reported when a real beat was seen within this window;
// otherwise we send "invalid" instead of echoing the last good value forever.
const unsigned long HR_TIMEOUT_MS = 4000;

// Diagnostic: peak MAX30102 FIFO occupancy (0–31) seen between status notifies.
// Near 0 => firmware drains as fast as the sensor fills (sensor-rate-limited);
// near 31 => the FIFO is backing up (firmware/link can't keep up, dropping).
byte maxFifo = 0;

// Sensor config read back after setup() — the ACTUAL sample rate (Hz), pulse
// width (us), and sample averaging the chip is running, vs what we asked for.
int cfgSR  = 0;
int cfgPW  = 0;
int cfgAvg = 0;

// Cumulative FIFO overflow count (register 0x05, OVF_COUNTER) this session. If
// this climbs, the chip produced more samples than the firmware read = we ARE
// dropping samples = the ~250 Hz limit is the firmware/link, not the sensor.
unsigned long ovfTotal = 0;

// Loop profiling (micros) — where does the wall-clock go? Reset each status
// window; reported as PROF=read/notify/spo2 (avg us/sample, avg us/raw-notify,
// last SpO2 call us). Reveals whether reads (sensor wait), BLE notify, or the
// SpO2 algorithm dominate the loop.
unsigned long profReadUs = 0, profReadN = 0;
unsigned long profNotifyUs = 0, profNotifyN = 0;
unsigned long profSpO2Us = 0;

// ---- Slow signals (temperature) ----
float tempC = 0;
unsigned long lastTempRead = 0;
const unsigned long TEMP_INTERVAL_MS = 5000;     // MAX30102 temp slow, ~once / 5 s

// ---- Raw waveform transmit buffers (PPG samples + beats since last notify) --
// We flush a packet every RAW_FLUSH_AT samples. Samples are now packed as 3 bytes
// each (18-bit ADC fits in 24 bits), so more fit per packet than the old 4-byte
// encoding. Worst-case packet must stay under the ~244 B MTU:
//   13 header + RAW_TX_MAX*6 (IR+Red, 3B each) + BEAT_TX_MAX*4
//   = 13 + 162 + 64 = 239 B.
const byte    RAW_TX_MAX   = 27;     // hard cap on samples buffered per packet
const byte    RAW_FLUSH_AT = 24;     // flush once this many have accumulated
uint32_t      rawIR[RAW_TX_MAX];
uint32_t      rawRed[RAW_TX_MAX];
byte          rawCount = 0;
unsigned long rawT0    = 0;          // real millis() of first sample in batch
unsigned long rawTlast = 0;          // real millis() of most recent sample
uint32_t      rawSeq   = 0;          // monotonic packet counter

const byte    BEAT_TX_MAX = 16;
unsigned long beatTx[BEAT_TX_MAX];   // absolute device-millis of recent beats
byte          beatTxCount = 0;

MAX30105 sensor;
BLECharacteristic*  dataChar = nullptr;
BLECharacteristic*  cmdChar  = nullptr;
BLECharacteristic*  rawChar  = nullptr;
BLEServer*          server   = nullptr;

unsigned long lastNotify = 0;
const unsigned long NOTIFY_INTERVAL_MS = 400;    // 2.5 Hz

// ============================================================================
//                                  Helpers
// ============================================================================

void resetHRState() {
    for (byte i = 0; i < HR_SAMPLES; i++) rates[i] = 0;
    rateIndex = 0;
    beatAvg = 0;
    beatsPerMinute = 0;
    lastBeat = 0;

    ibiCount = 0;
    ibiHead  = 0;

    hrHistCount = 0;
    hrHistHead  = 0;
    lastGoodHR  = -1;
    lastGoodHRTime = 0;

    validHR = 0;
    validSPO2 = 0;
    hrFromAlgo = 0;
    spo2 = 0;

    rawCount    = 0;
    rawTlast    = 0;
    beatTxCount = 0;

    lastSpO2Calc = 0;
}

void startSampling() {
    if (!sensorOk) return;
    if (sampling)   return;
    sensor.wakeUp();
    delay(20);
    while (sensor.available()) {
        sensor.getRed();
        sensor.getIR();
        sensor.nextSample();
    }
    resetHRState();
    samplesCollected = 0;
    rawSeq = 0;              // fresh raw-stream sequence for this session
    ovfTotal = 0;            // fresh overflow count for this session
    sampling = true;
}

void stopSampling() {
    if (!sampling) return;
    if (sensorOk)  sensor.shutDown();
    sampling = false;
    samplesCollected = 0;
    resetHRState();
}

const char* readChargeState() {
    bool charging = (digitalRead(PIN_CHRG)  == LOW);
    bool full     = (digitalRead(PIN_STDBY) == LOW);
    if (charging && !full) return "charging";
    if (full && !charging) return "full";
    if (!charging && !full) return "battery";
    return "fault";
}

// Read one MAX30102 register directly over I2C (for config readback). The
// sensor's I2C address is 0x57.
uint8_t readSensorReg(uint8_t reg) {
    Wire.beginTransmission((uint8_t)0x57);
    Wire.write(reg);
    Wire.endTransmission(false);          // repeated start, keep bus
    Wire.requestFrom((uint8_t)0x57, (uint8_t)1);
    return Wire.available() ? Wire.read() : 0;
}

// Perfusion Index — pulsatile amplitude as a % of DC level over the SpO2 buffer
float computePerfusionIndex() {
    if (samplesCollected < SPO2_BUF_LEN) return 0.0f;
    uint32_t irMax = 0, irMin = UINT32_MAX;
    uint64_t irSum = 0;
    for (int i = 0; i < SPO2_BUF_LEN; i++) {
        uint32_t v = irBuffer[i];
        if (v > irMax) irMax = v;
        if (v < irMin) irMin = v;
        irSum += v;
    }
    float mean = (float)irSum / SPO2_BUF_LEN;
    if (mean < 1.0f) return 0.0f;
    return 100.0f * ((float)(irMax - irMin)) / mean;
}

// HRV (RMSSD) over the buffered IBIs — root-mean-square of successive differences
float computeRMSSD() {
    if (ibiCount < 3) return 0.0f;
    // Walk the circular buffer in order
    long sumSq = 0;
    byte n = 0;
    byte prevIdx = ibiHead;
    if (prevIdx == 0) prevIdx = IBI_BUF - 1;
    else              prevIdx -= 1;
    // Start from the oldest entry; if buffer not full, start at index 0
    byte start = (ibiCount < IBI_BUF) ? 0 : ibiHead;
    long prev = (long)ibis[start];
    for (byte i = 1; i < ibiCount; i++) {
        byte idx = (start + i) % IBI_BUF;
        long cur = (long)ibis[idx];
        long diff = cur - prev;
        sumSq += diff * diff;
        prev = cur;
        n++;
    }
    if (n == 0) return 0.0f;
    return sqrtf((float)sumSq / (float)n);
}

void pushIBI(unsigned long ms) {
    ibis[ibiHead] = ms;
    ibiHead = (ibiHead + 1) % IBI_BUF;
    if (ibiCount < IBI_BUF) ibiCount++;
}

// Median of last N HRs (insertion sort — N is tiny)
int hrMedian() {
    if (hrHistCount == 0) return -1;
    int tmp[HR_MEDIAN];
    for (byte i = 0; i < hrHistCount; i++) tmp[i] = hrHistory[i];
    for (byte i = 1; i < hrHistCount; i++) {
        int v = tmp[i]; byte j = i;
        while (j > 0 && tmp[j-1] > v) { tmp[j] = tmp[j-1]; j--; }
        tmp[j] = v;
    }
    return tmp[hrHistCount / 2];
}

void pushHR(int hr) {
    hrHistory[hrHistHead] = hr;
    hrHistHead = (hrHistHead + 1) % HR_MEDIAN;
    if (hrHistCount < HR_MEDIAN) hrHistCount++;
}

// Apply species range + rate-of-change limit; returns -1 if rejected.
int applyOutlierFilter(int candidate) {
    if (candidate < prof().hrMin || candidate > prof().hrMax) return -1;
    unsigned long now = millis();
    if (lastGoodHR > 0) {
        unsigned long dt = now - lastGoodHRTime;
        if (dt == 0) dt = 1;
        int allowed = (int)((unsigned long)prof().maxHrChangeBpm * dt / 1000UL) + 5;
        if (abs(candidate - lastGoodHR) > allowed) return -1;
    }
    lastGoodHR = candidate;
    lastGoodHRTime = now;
    return candidate;
}

// ============================================================================
//                              BLE callbacks
// ============================================================================

class CmdCallbacks : public BLECharacteristicCallbacks {
    void onWrite(BLECharacteristic* c) override {
        String val = c->getValue();
        val.trim();
        String upper = val;
        upper.toUpperCase();

        if (upper == "START") {
            startSampling();
        } else if (upper == "STOP") {
            stopSampling();
        } else if (upper.startsWith("SPECIES:")) {
            String sp = upper.substring(8);
            sp.trim();
            if (sp == "HUMAN")    { species = SPECIES_HUMAN;    resetHRState(); }
            if (sp == "MARMOSET") { species = SPECIES_MARMOSET; resetHRState(); }
        }
    }
};

class ServerCallbacks : public BLEServerCallbacks {
    void onConnect(BLEServer* s) override {
        deviceConnected = true;
    }
    void onDisconnect(BLEServer* s) override {
        deviceConnected = false;
        stopSampling();
        BLEDevice::startAdvertising();
    }
};

// ============================================================================
//                              Sample / loop
// ============================================================================

void readOneSampleIntoBuffer(int pos) {
    while (!sensor.available()) sensor.check();
    uint32_t ir  = sensor.getIR();
    uint32_t red = sensor.getRed();
    redBuffer[pos] = red;
    irBuffer[pos]  = ir;

    // Stash the raw optical sample for the next RAW notify (pre-bpm waveform),
    // recording the real read time so the host sees the true sample cadence.
    if (rawCount < RAW_TX_MAX) {
        unsigned long nowMs = millis();
        if (rawCount == 0) rawT0 = nowMs;
        rawTlast = nowMs;
        rawIR[rawCount]  = ir;
        rawRed[rawCount] = red;
        rawCount++;
    }

    if (checkForBeat(ir)) {
        long now = millis();
        long delta = now - lastBeat;
        // Refractory: ignore peaks too soon after previous beat (dicrotic notch)
        if (delta < prof().refractoryMs) return;
        lastBeat = now;
        float bpm = 60000.0f / (float)delta;
        if (bpm > prof().hrMin && bpm < prof().hrMax) {
            int filtered = applyOutlierFilter((int)bpm);
            if (filtered > 0) {
                pushHR(filtered);
                pushIBI((unsigned long)delta);
                // Record the confirmed beat time for the next RAW notify.
                if (beatTxCount < BEAT_TX_MAX) beatTx[beatTxCount++] = (unsigned long)now;
                rates[rateIndex % HR_SAMPLES] = (byte)min(filtered, 255);
                rateIndex++;
                int sum = 0;
                byte n = (rateIndex < HR_SAMPLES) ? rateIndex : HR_SAMPLES;
                for (byte i = 0; i < n; i++) sum += rates[i];
                beatAvg = sum / n;
                beatsPerMinute = (float)filtered;
            }
        }
    }
    sensor.nextSample();
}

void sampleStep() {
    if (!sensorOk || !sampling) return;
    if (samplesCollected < SPO2_BUF_LEN) {
        readOneSampleIntoBuffer(samplesCollected);
        samplesCollected++;
        if (samplesCollected == SPO2_BUF_LEN) {
            // First full buffer: compute SpO2 once and start the slow cadence.
            maxim_heart_rate_and_oxygen_saturation(
                irBuffer, SPO2_BUF_LEN, redBuffer,
                &spo2, &validSPO2, &hrFromAlgo, &validHR);
            lastSpO2Calc = millis();
        }
        return;
    }
    // Diagnostic: sample the chip-FIFO occupancy BEFORE we drain it this cycle.
    // (writePtr - readPtr) mod 32 = samples waiting in the sensor's FIFO.
    byte occ = (byte)((sensor.getWritePointer() - sensor.getReadPointer()) & 0x1F);
    if (occ > maxFifo) maxFifo = occ;
    // OVF_COUNTER (0x05) counts samples lost to overflow since the last FIFO
    // read; read it BEFORE draining (which resets it) and accumulate. A growing
    // total = the chip outran the firmware (definitive "we're dropping" signal).
    ovfTotal += (unsigned long)(readSensorReg(0x05) & 0x1F);

    // Steady state: slide the buffer and read fresh samples every cycle so the
    // beat detector (inside readOneSampleIntoBuffer) sees a continuous stream.
    for (byte i = SAMPLES_PER_ITER; i < SPO2_BUF_LEN; i++) {
        redBuffer[i - SAMPLES_PER_ITER] = redBuffer[i];
        irBuffer[i - SAMPLES_PER_ITER]  = irBuffer[i];
    }
    unsigned long _mr = micros();                // profile the read batch
    for (byte i = SPO2_BUF_LEN - SAMPLES_PER_ITER; i < SPO2_BUF_LEN; i++) {
        readOneSampleIntoBuffer(i);
    }
    profReadUs += micros() - _mr;
    profReadN  += SAMPLES_PER_ITER;
    // Run the expensive SpO2 algorithm only on its slow cadence — this is the
    // one heavy call, so keeping it off the per-cycle path is what restores
    // continuous PPG sampling (and reliable beat detection).
    if (millis() - lastSpO2Calc >= SPO2_INTERVAL_MS) {
        unsigned long _ms = micros();
        maxim_heart_rate_and_oxygen_saturation(
            irBuffer, SPO2_BUF_LEN, redBuffer,
            &spo2, &validSPO2, &hrFromAlgo, &validHR);
        profSpO2Us = micros() - _ms;             // last SpO2 call duration
        lastSpO2Calc = millis();
    }
}

// ============================================================================
//                              Notification packet
// ============================================================================

void sendStatusNotify() {
    if (!deviceConnected || dataChar == nullptr) return;

    char packet[220];          // room for the diagnostic fields (FIFO/OVF/CFG/PROF)
    const char* chg = readChargeState();
    const char* sp  = prof().label;

    if (!sensorOk) {
        snprintf(packet, sizeof(packet),
                 "SENSOR=error,CHARGE=%s,SPECIES=%s", chg, sp);
    } else if (!sampling) {
        snprintf(packet, sizeof(packet),
                 "SAMPLING=0,HR=-1,SPO2=-1,AVG=0,VALID=0,"
                 "CHARGE=%s,SPECIES=%s", chg, sp);
    } else if (samplesCollected < SPO2_BUF_LEN) {
        int pct = (samplesCollected * 100) / SPO2_BUF_LEN;
        snprintf(packet, sizeof(packet),
                 "SAMPLING=1,HR=-1,SPO2=-1,AVG=0,VALID=0,WARMUP=%d,"
                 "CHARGE=%s,SPECIES=%s", pct, chg, sp);
    } else {
        uint32_t latestIR = irBuffer[SPO2_BUF_LEN - 1];
        bool fingerOn    = latestIR >= FINGER_THRESHOLD;

        float pi    = computePerfusionIndex();
        int displaySpO2 = validSPO2 ? (int)spo2 : -1;

        // HR / HRV are trustworthy only if a real beat was detected recently.
        // When the beat detector goes quiet (weak signal, motion), report
        // invalid rather than echoing the last good value indefinitely.
        bool hrFresh = (lastGoodHR > 0) &&
                       (millis() - lastGoodHRTime < HR_TIMEOUT_MS);
        int   median    = hrMedian();
        int   reportHR  = (hrFresh && median > 0) ? median : -1;
        int   reportAvg = hrFresh ? beatAvg : 0;
        float reportHrv = hrFresh ? computeRMSSD() : 0.0f;

        bool piOk = (pi >= prof().piMinPct);
        bool ok   = fingerOn && piOk && validSPO2 && hrFresh;

        if (!fingerOn) {
            snprintf(packet, sizeof(packet),
                     "SAMPLING=1,HR=-1,SPO2=-1,AVG=0,VALID=0,PI=%.1f,"
                     "TEMP=%.1f,HRV=0,SPECIES=%s,CHARGE=%s",
                     pi, tempC, sp, chg);
        } else {
            snprintf(packet, sizeof(packet),
                     "SAMPLING=1,HR=%d,SPO2=%d,AVG=%d,VALID=%d,PI=%.1f,"
                     "TEMP=%.1f,HRV=%.0f,SPECIES=%s,CHARGE=%s",
                     reportHR, displaySpO2, reportAvg, (int)ok,
                     pi, tempC, reportHrv, sp, chg);
        }
    }

    // Append the FIFO-occupancy + cumulative overflow diagnostics while sampling
    // (auto-appears in the GUI footer). Reset the running peak after each report;
    // OVF is cumulative for the session (a climbing value = dropped samples).
    if (sampling && sensorOk) {
        size_t len = strlen(packet);
        snprintf(packet + len, sizeof(packet) - len,
                 ",FIFO=%d,OVF=%lu", maxFifo, ovfTotal);
        maxFifo = 0;
    }
    // Append the config readback (actual sample rate / pulse width) so we can
    // see, live in the GUI footer, what the chip is really set to.
    if (sensorOk && cfgSR > 0) {
        size_t len = strlen(packet);
        snprintf(packet + len, sizeof(packet) - len,
                 ",CFG=%d/%d/%d", cfgSR, cfgPW, cfgAvg);   // sr/pw/avg
    }
    // Loop profile: avg us/sample read, avg us/raw-notify, last SpO2 us. Reset
    // the accumulators each window so PROF reflects the most recent ~400 ms.
    if (sampling && sensorOk) {
        unsigned long rdus = profReadN   ? profReadUs   / profReadN   : 0;
        unsigned long nfus = profNotifyN ? profNotifyUs / profNotifyN : 0;
        size_t len = strlen(packet);
        snprintf(packet + len, sizeof(packet) - len,
                 ",PROF=%lu/%lu/%lu", rdus, nfus, profSpO2Us);
        profReadUs = profReadN = profNotifyUs = profNotifyN = 0;
    }

    dataChar->setValue((uint8_t*)packet, strlen(packet));
    dataChar->notify();
}
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
void loop() {
    sampleStep();

    // Flush the raw waveform once a batch has accumulated. Larger batches mean
    // fewer BLE notifications per second, which keeps the link stable at high
    // sample rates (and we never exceed RAW_TX_MAX / the MTU).
    if (sampling && rawCount >= RAW_FLUSH_AT) sendRawNotify();

    // Slow signal: temperature roughly every 5 seconds when sensor is on
    if (sensorOk && sampling && millis() - lastTempRead > TEMP_INTERVAL_MS) {
        tempC = sensor.readTemperature();
        lastTempRead = millis();
    }

    if (millis() - lastNotify >= NOTIFY_INTERVAL_MS) {
        lastNotify = millis();
        sendStatusNotify();
        sendRawNotify();
    }

    if (!sampling) delay(10);
}

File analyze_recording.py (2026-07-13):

"""
Offline PPG analysis of a HealthMonitor recording, using NeuroKit2.

The rigorous counterpart to the GUI's live detector. It loads a `<name>_raw.csv`
(the full-rate raw PPG the GUI records) and:

  1. Splits the recording into device-clock SESSIONS at reboots and long gaps.
     (The device's millis() clock resets if it reboots — e.g. a flaky link or a
     draining battery — and disconnects leave gaps. Each session has its own
     clean, monotonic clock.)
  2. Within each session, gates out bad data — finger-off stretches and
     low-perfusion / motion segments — with a quality check that mirrors the
     firmware (IR DC level for finger presence + a perfusion-index threshold on
     the pulse band), then time-slices into contiguous GOOD segments.
     This matters because HRV must never be computed across a gap: a finger-off
     pause creates one enormous fake inter-beat interval that wrecks RMSSD.
  3. Per segment: species-aware bandpass + peak detection, NeuroKit Kubios
     artifact correction, then HRV.
  4. Reports usable vs. discarded time, a per-segment table, a gap-safe pooled
     HRV summary, and the full NeuroKit HRV suite on the longest clean segment.

Why custom peak detection instead of nk.ppg_peaks? NeuroKit's built-in PPG
detectors are validated on human data and assume human-scale timing; the
species-aware passband/refractory here also handle marmosets (~150-400 bpm).

Usage:
    pip install neurokit2 scipy numpy
    python analyze_recording.py <name>_raw.csv [--species human|marmoset]

Species is auto-detected from the companion status CSV (`<name>.csv`) when
present; --species overrides it.
"""
import argparse
import csv
import sys
from collections import Counter
from pathlib import Path

try:
    import numpy as np
except ImportError:
    sys.exit("Missing dependency: pip install numpy")
try:
    from scipy.signal import butter, filtfilt, find_peaks
except ImportError:
    sys.exit("Missing dependency: pip install scipy")
try:
    import neurokit2 as nk
except ImportError:
    sys.exit("Missing dependency: pip install neurokit2")

FINGER_THRESHOLD = 50000   # raw IR DC level for "finger on" (matches firmware)
QUALITY_WIN_S = 1.0        # window for the finger/perfusion quality check
MIN_SEGMENT_S = 20.0       # shortest clean run worth an HRV estimate
SESSION_GAP_MS = 2000.0    # a forward time jump bigger than this splits a session

# Mirrors SPECIES_PROFILES in health_monitor_gui.py (and the firmware PROFILES).
SPECIES_PROFILES = {
    "human":    {"hr_min": 30,  "hr_max": 220, "refractory_ms": 300, "max_hr_change": 30, "pi_min": 0.5},
    "marmoset": {"hr_min": 150, "hr_max": 400, "refractory_ms": 100, "max_hr_change": 60, "pi_min": 0.4},
}


def load_raw(raw_path: Path):
    """Return (device_t_ms array, IR array) from a _raw.csv."""
    t_ms, ir = [], []
    with raw_path.open() as f:
        for row in csv.DictReader(f):
            try:
                t_ms.append(int(row["device_t_ms"]))
                ir.append(float(row["ir"]))
            except (KeyError, ValueError):
                continue
    if len(t_ms) < 10:
        sys.exit(f"Too few samples in {raw_path.name}")
    return np.array(t_ms, dtype=float), np.array(ir, dtype=float)


def detect_species(raw_path: Path) -> str | None:
    """Most common 'species' value in the companion status CSV, if any."""
    status = raw_path.with_name(raw_path.name.replace("_raw.csv", ".csv"))
    if not status.exists():
        return None
    vals = []
    try:
        with status.open() as f:
            for row in csv.DictReader(f):
                v = (row.get("species") or "").strip().lower()
                if v:
                    vals.append(v)
    except OSError:
        return None
    return Counter(vals).most_common(1)[0][0] if vals else None


def split_sessions(t_ms):
    """Split where the device clock jumps backward (reboot) or forward by more
    than SESSION_GAP_MS (a disconnect gap). Returns list of (i0, i1) ranges."""
    d = np.diff(t_ms)
    breaks = np.where((d < 0) | (d > SESSION_GAP_MS))[0] + 1
    bounds = np.concatenate(([0], breaks, [len(t_ms)]))
    return [(int(bounds[k]), int(bounds[k + 1])) for k in range(len(bounds) - 1)]


def bandpass(sig, fs, prof):
    """Species-aware pulse-band filter, or None if fs is too low for the band."""
    lo = prof["hr_min"] / 60.0
    hi = min(prof["hr_max"] / 60.0, fs / 2.0 - 0.2)
    if hi <= lo:
        return None
    b, a = butter(2, [lo, hi], btype="band", fs=fs)
    return filtfilt(b, a, sig)


def quality_mask(raw_g, bp, fs, pi_min):
    """Per-sample good/bad mask. A window is GOOD when the IR DC level shows a
    finger is present AND the pulse-band amplitude (a perfusion index on the
    bandpassed signal, so baseline wander/motion don't fake it) clears pi_min."""
    n = len(raw_g)
    w = max(1, int(QUALITY_WIN_S * fs))
    mask = np.zeros(n, dtype=bool)
    for start in range(0, n, w):
        sl = slice(start, min(start + w, n))
        dc = float(np.mean(raw_g[sl]))
        if dc < FINGER_THRESHOLD:
            continue
        if 100.0 * float(np.ptp(bp[sl])) / dc >= pi_min:   # pulsatility %
            mask[sl] = True
    return mask


def find_segments(mask, min_len):
    """Contiguous True runs of at least min_len samples, as (i0, i1) ranges."""
    segs, i, n = [], 0, len(mask)
    while i < n:
        if mask[i]:
            j = i
            while j < n and mask[j]:
                j += 1
            if j - i >= min_len:
                segs.append((i, j))
            i = j
        else:
            i += 1
    return segs


def refine_peaks(sig, peaks):
    """Sub-sample peak refinement by parabolic interpolation. Fits a parabola
    through each peak and its two neighbours; the vertex gives a fractional
    sample position. This sharpens inter-beat timing below the sample period
    (important at lower rates / faster hearts, e.g. marmoset HRV). Returns
    fractional positions (same length as peaks)."""
    pos = peaks.astype(float)
    for k, i in enumerate(peaks):
        if 0 < i < len(sig) - 1:
            y0, y1, y2 = sig[i - 1], sig[i], sig[i + 1]
            denom = y0 - 2.0 * y1 + y2
            if denom != 0:
                delta = 0.5 * (y0 - y2) / denom
                if -0.5 <= delta <= 0.5:        # guard: true vertex is within ±0.5
                    pos[k] = i + delta
    return pos
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

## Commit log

2026-06-15 Initial commit: ESP32-S3 health monitor with BLE + LSL streaming
2026-07-13 Add PC-side HRV pipeline, binary raw PPG streaming, and sensor diagnostics
    Firmware (ESP32_HealthMonitor.ino):
    - Stream raw PPG on a dedicated BLE characteristic as compact binary (3-byte
    samples) with real per-sample timestamps and beat markers
    - Honest HR/HRV reporting (invalid when no recent beat); per-species profiles
    - SpO2 on a slow cadence; diagnostics: CFG register readback (rate/pulse/avg),
    FIFO occupancy, OVF overflow counter, micros() loop profiling
    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
2026-07-13 Update README for the new pipeline; move sketch into ESP32_HealthMonitor/ subfolder
    - README: document raw-PPG binary streaming, PC-side HR/HRV detection, the offline
    NeuroKit2 analyzer, the CFG/FIFO/OVF/PROF diagnostics, sample-rate findings
    (~250 Hz sensor limit), and measured battery/brownout behaviour
    - Move ESP32_HealthMonitor.ino into a same-named subfolder so `git clone` opens
    directly in the Arduino IDE (no "move to sketch folder" prompt)
    [ESP32_HealthMonitor.ino]
2026-09-14 Add NewBoard hardware docs (schematic V3, BOM, pick-and-place, board photos, programming jig CAD, user guide), New_HR, schematic block diagram
    Synced from Z:/Playground/ESP32_HealthMonitor. Canonical copy now lives in
    Feng-Lab-MIT/MarmoFACT/ESP32_HealthMonitor.
    [BOM_FLEX.xlsx, PickAndPlace_FLEX.xlsx, pogo_jig.scad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]
